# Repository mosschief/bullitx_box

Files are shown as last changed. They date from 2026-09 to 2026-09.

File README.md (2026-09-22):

# Bullitt X cargo box panels

Vermoot's plywood box for the Original Bullitt, stretched to fit a Bullitt X.

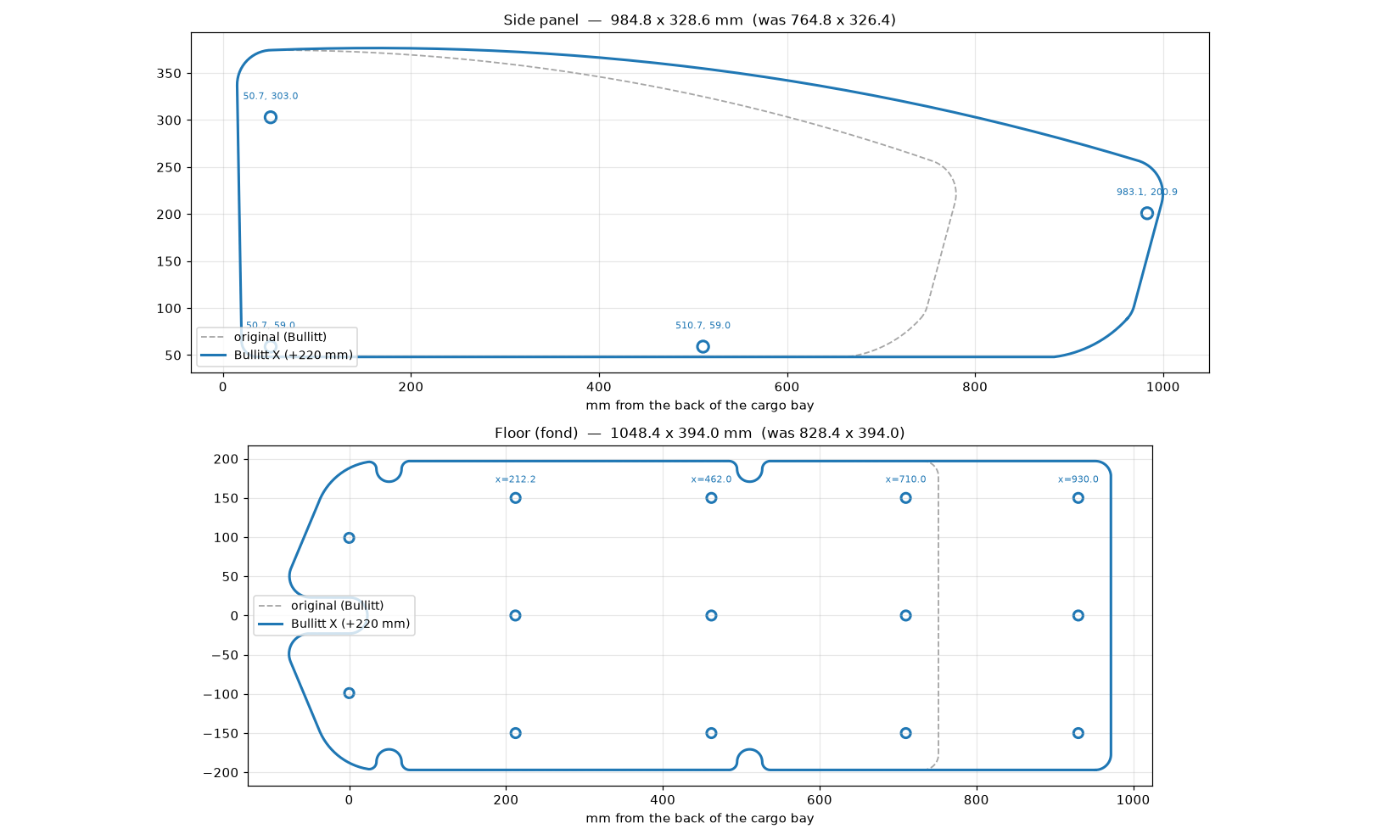
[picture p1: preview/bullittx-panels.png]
panels


## What changed, and why

The Bullitt X cargo bay is **220 mm longer than the Original Bullitt, and all of
the extra length is at the front**. Three things agree on this:

| | Original Bullitt | Bullitt X |
|---|---|---|
| Cargo bed at base (Larry vs Harry spec) | 710 mm | 930 mm |
| Cargo bed at top (Larry vs Harry spec) | 824 mm | 1044 mm |
| Total bike length (Larry vs Harry spec) | 2430 mm | 2650 mm |
| Floor transverses (from the two CAD models) | 3, at 212 / 462 / 710 | 4, at 212 / 462 / 712 / 932 |
| Inner width between the frame rails | 401 mm | 401 mm |

Line the two frames up by the back of the cargo bay and the Bullitt X's rear
cross brace and its first three floor transverses land on the Original's within
2 mm. The fourth transverse is new, 220 mm further forward. Bed top minus bed
base is 114 mm on both bikes, so the front and back walls lean at the same angle
and those two panels do not change at all.

So the panels are **not scaled**. Each one is cut through its straight middle
section and the front half is slid forward 220 mm. Every profile, radius and
bolt position at either end is exactly as Vermoot drew it.

## Files

Cut these two from 10 mm plywood, same as the originals:

- `panels/Side panel X.dxf` — 984.8 x 328.6 mm (was 764.8 x 326.4). Cut two, mirrored.
- `panels/fond X.dxf` — floor, 1048.4 x 394.0 mm (was 828.4 x 394.0).

**Unchanged — use Vermoot's originals as they are:** `front panel.dxf`,
`back panel.dxf`, `front link.stl`, `back link.stl`, `bottom link.stl`. They are
not copied into this repo; the design is Vermoot's and you already have it. Print
the same four bottom links, two back links and two front links as before.

## Bolt positions

x is measured from the back of the cargo bay, the same datum both DXFs already use.

**Side panel** — bottom-link bolts at x = 50.7 and 510.7 (both at y = 59),
back-link bolt at 50.7 / 303, front-link bolt at **983.1** / 200.9. Only the
front-link bolt moves; the other three are Vermoot's, untouched.

**Floor** — bolt rows at x = 212.2, 462, 710 and **930**, three bolts per row at
y = 0 and +/- 150. The first three rows are Vermoot's, unchanged; 930 is the new
fourth transverse. The two pairs of semicircular reliefs in the floor edge are
Vermoot's too, and stay where they are (see below).

## How the box hangs on the frame

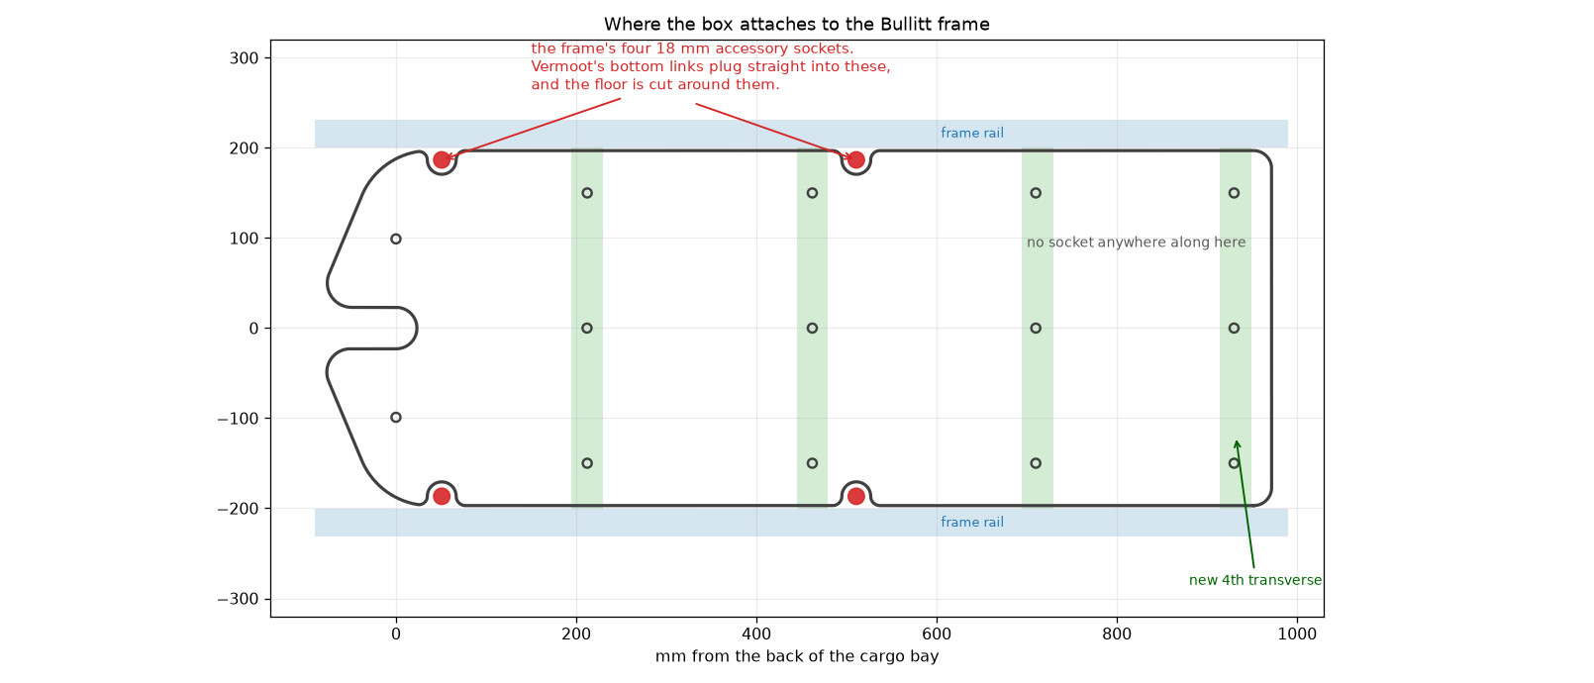
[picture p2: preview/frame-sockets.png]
frame sockets


The Bullitt frame has two cross tubes inside the cargo bay, at x = 50.8 and
510.8, each with an 18 mm vertical socket near either end at y = +/- 186.7.
**Vermoot's bottom link is a solid 18 mm peg that plugs into one of those
sockets** — it is not a clamp, and it will not mount anywhere else on the rail.
That is also what the semicircular reliefs in the floor edge are for: they clear
the socket and the foot of the link.

So the side panels have exactly four mounting points along the bottom and they
are fixed by the frame, not by the panel. A longer panel does not get more of
them. If your Bullitt X turns out to have a third pair of sockets further
forward, measure where they are and re-run the script with
`--extra-link-x <that x>`; it will add the panel bolt and the matching floor
relief. Otherwise the stretched panel runs unsupported along the bottom from
510.7 to the front link, 472 mm, which is 233 mm more than the original.

## Check this one dimension before you cut

The front-link bolt is at x = 983.1, which is Vermoot's 763.1 plus 220. The
Bullitt X model in `BullittX.FCStd` puts the front cross member about **9 mm
further forward and 9 mm lower** than a clean 220 mm shift predicts. That is
within the disagreement you would expect between two hand-built models — the
Bullitt model in the Vermoots project has its own cross beams at 250 and 248 mm
pitch, and puts the bed base at 715 mm where Larry vs Harry say 710 — but it
lands on the one hole that has no second bolt to average it out.

The cheap fix: cut the panel, offer it up, and drill the front-link hole last,
through the bracket, on the bike. Otherwise measure from the back of the bay to
the front link mount and compare with 983.

## Rebuilding the files

```
pip install ezdxf
python3 tools/make_bullittx_panels.py <folder with Vermoot's DXFs> panels/
python3 tools/preview.py <that folder> preview/bullittx-panels.png
```

`--extension` is the 220 mm, if you measure something different on your own bike.
`--extra-link-x` adds a bottom-link station, if your frame has a third socket pair.

## Cutting it on a CNC

`cnc/` has everything nested and ready to cut from 1/2" ply on a Shapeoko: the sheet
layouts as DXF and SVG, G-code, and the changes the thicker ply needs. Start with
[cnc/README.md](cnc/README.md).

## Fit check

`preview/fit-check.png` is the new geometry drawn over the Bullitt X frame from
`BullittX.FCStd`, aligned on the back of the cargo bay. The floor bolt rows
should sit on the red transverse marks.

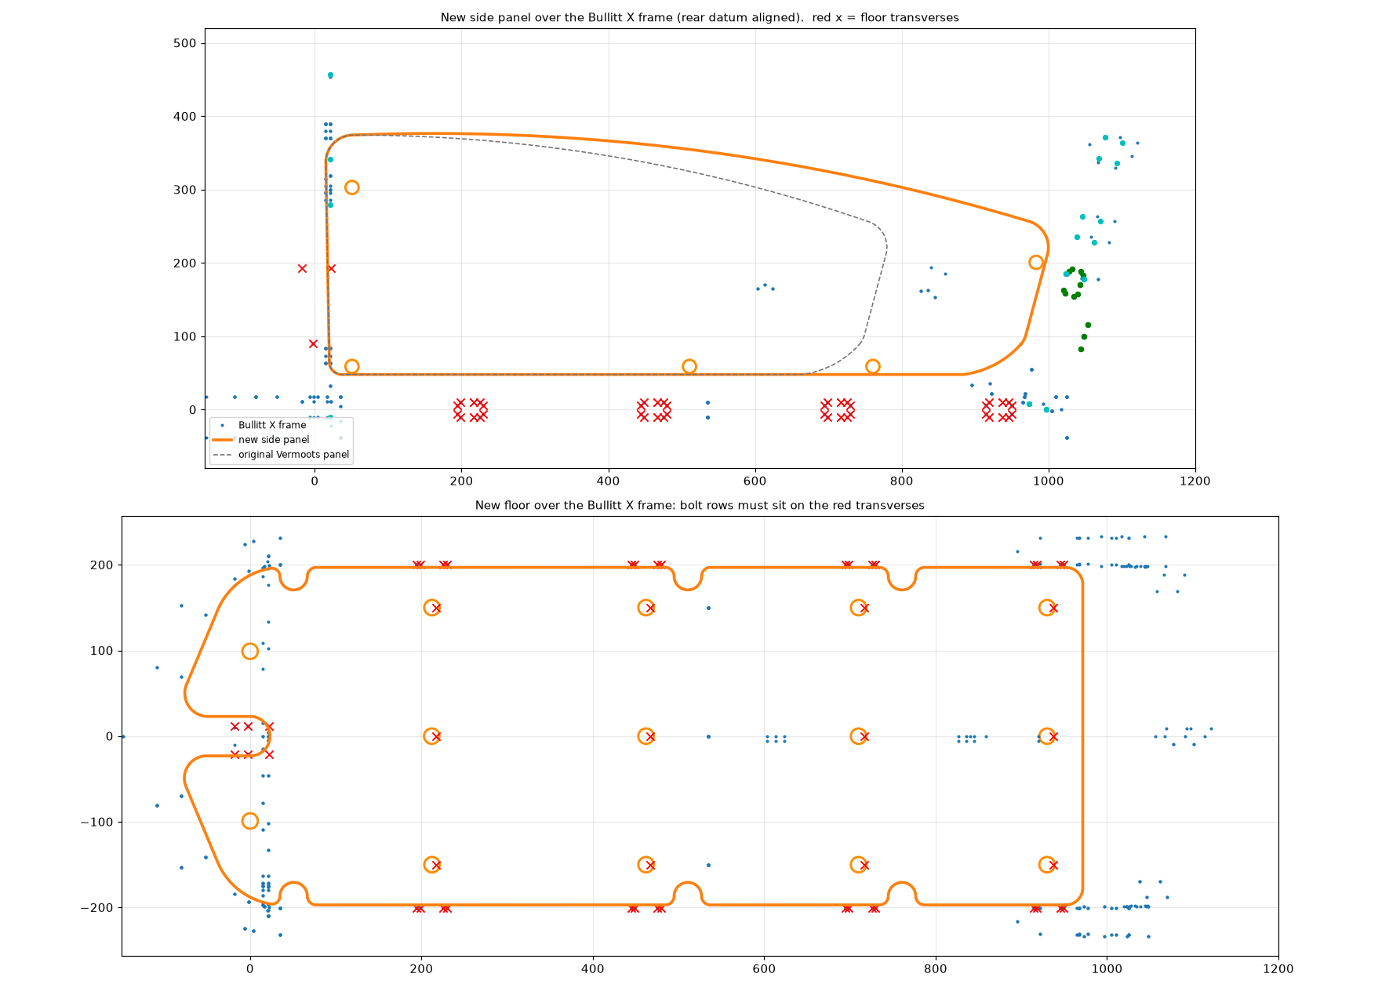
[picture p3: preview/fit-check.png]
fit check


## Child seat

The Larry vs Harry foldable seat bolts to the frame, not to the box, so the
220 mm stretch does not affect it and the Bullitt X gives it more room than a
standard Bullitt. What is worth checking before you commit: the box already
occupies all four of the frame sockets above, so if the seat wants the same
sockets, the two compete. The seat's own manual has its struts bolting to
"holes in the frame" from the outer side, and its lower bracket clamping the
shoulder tubes, which reads like a different set of mounting points — but that
is not confirmed. Dry-fit the seat before final assembly.

## Credit

The box design, the panel shapes and the three printed links are Vermoot's
"Plateformes Bullitt". This repo holds the two panels that had to change length,
the scripts that change them, and (under `cnc/`) all five panels adjusted and
nested for 1/2" ply.

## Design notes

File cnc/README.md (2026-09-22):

# Cutting the Bullitt X box on a Shapeoko 5 Pro from 1/2" ply

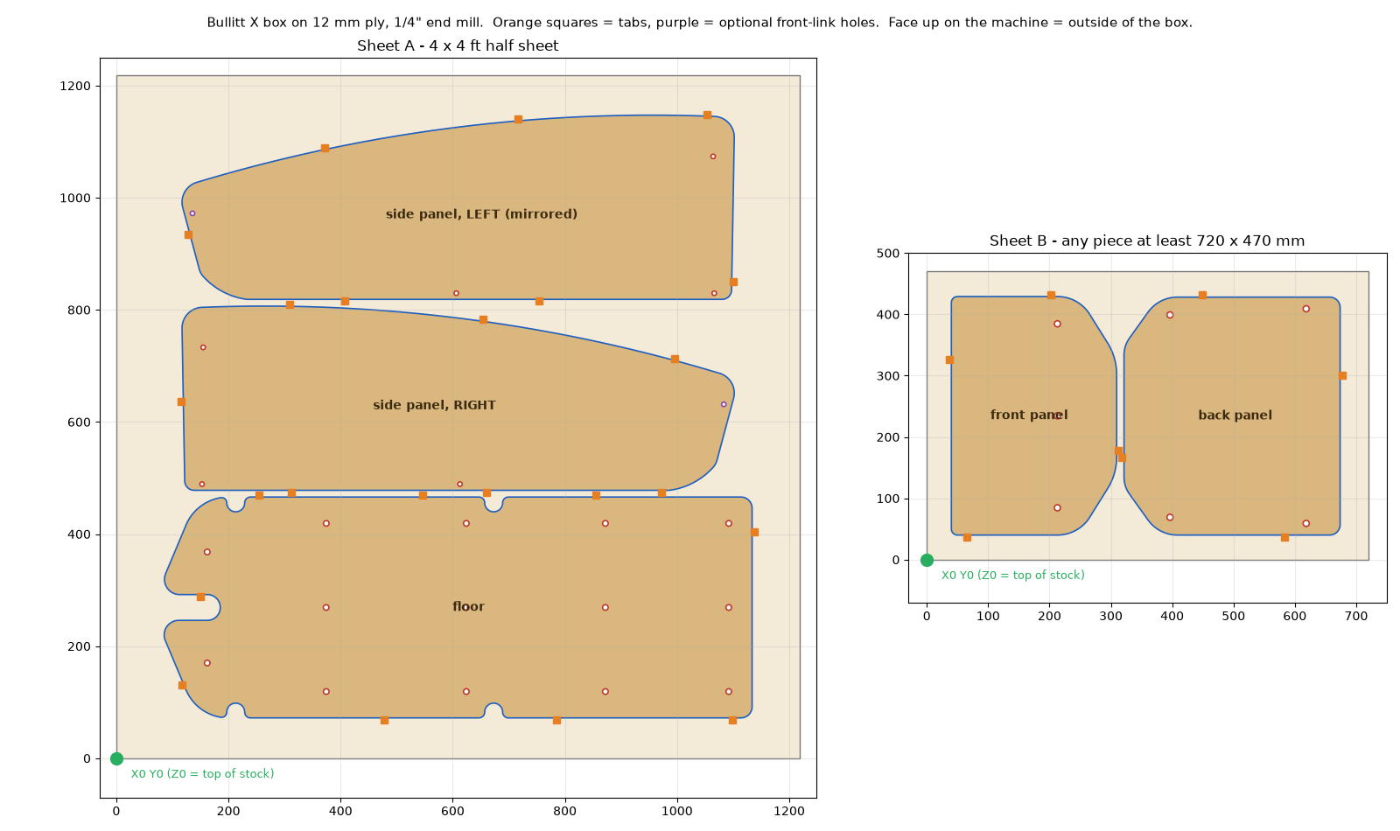
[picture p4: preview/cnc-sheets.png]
cut sheets


## It takes a half sheet plus a smaller piece

The floor and both side panels fill a 4 x 4 ft half sheet. The front and back
panels do not fit in what is left: the floor (394 mm) and the two side panels
(329 mm each) already use about 1075 mm of the 1219 mm, even nested tightly, and
the smallest side of the front panel is 271 mm. So:

| Sheet | Parts | Stock |
|---|---|---|
| **A** | floor, right side panel, left side panel | 4 x 4 ft half sheet |
| **B** | front panel, back panel | any piece at least **720 x 470 mm** (28.5 x 18.5 in); a 2 x 4 ft piece is plenty |

## Measure the ply, then pick the files

"1/2 inch" ply is usually 11.9 mm (15/32") or 12 mm (Baltic birch), sometimes a true
12.7 mm. Measure it with calipers in a few places and use the matching G-code:

| Measured thickness | Use |
|---|---|
| 11.7 to 12.3 mm | `gcode/*_12mm-stock.nc` (cuts 12.5 mm deep) |
| 12.4 to 13.0 mm | `gcode/*_12.7mm-stock.nc` (cuts 13.2 mm deep) |

Both cut about 0.5 mm into the spoilboard and leave 3 mm tabs.

## Machine setup

- **Tool:** 1/4" (6.35 mm) two-flute flat end mill. An upcut (Carbide 3D #201) works;
  a compression bit gives cleaner faces on both sides of the ply.
- **Spindle:** 18,000 rpm. On the Carbide router, set the dial by hand; the file sends `S18000`.
- **Feeds:** 1500 mm/min (59 ipm) cutting, 400 mm/min plunge, 800 mm/min in the holes,
  2.5 mm per lap. Deliberately conservative for a first run. Turn the feed override up
  if it sounds happy.
- **Zero:** X0 Y0 at the **front-left corner of the stock**, Z0 on the **top of the stock**.
  The BitZero corner probe does all three at once.
- **Safe height:** 15 mm above the stock. Keep clamps below that or out of the way of
  the parts.
- **Workholding:** every part stays attached by tabs (10 mm long, 3 mm thick; 9 on the
  floor, 7 per side panel, 4 each on the front and back). Screw the sheet down around the
  edge. Sheet A has at least 65 mm of clear margin all the way round. Put a few screws in
  the middle strips too if the sheet bows.

Each file cuts all its holes first, then each part outline. The outline is cut by
spiralling down 2.5 mm per lap with no plunges, followed by one clean-up lap at full
depth. Holes are helically bored with the same 1/4" bit (8 mm and 10 mm holes).

Rough run times at 100% feed: sheet A about 40 min, sheet B about 15 min.

## Run order

**Sheet A** (half sheet)
1. `sheet-A_floor-and-sides_front-link-holes-optional_<t>.nc`: **only if you want the
   front-link holes cut by the machine** (see below). Leave zero where it is.
2. `sheet-A_floor-and-sides_<t>.nc`

**Sheet B** (front/back piece)
1. `sheet-B_front-and-back_<t>.nc`

Cut the tabs with a flush-trim saw or chisel and sand them flush.

### The optional front-link holes

The side panel's front-link hole is the one dimension the previous check could not
pin down. The frame model puts that mount about 9 mm off where a clean 220 mm stretch
predicts. So it is in a separate file:

- Measure your bike first: the front link mount should be about 981 mm from the back
  of the cargo bay (the datum the main README uses). If it matches, run the optional file.
- If you're not sure, skip it, fit the panels, and drill the 8 mm hole through the bracket
  on the bike.

They are the purple holes in the picture above, and on their own layer
(`HOLES_front_link_optional`) in the DXF.

## Which side is which

Everything is cut with the **good face up**, so the face on top becomes the **outside**
of the box. The middle panel on sheet A is the **right** side panel (as Vermoot drew it)
and the top one is the **left** (mirrored). The floor, front and back panels are symmetric,
so either face can go up.

## What changed for 1/2" ply

The design was drawn for 10 mm ply. I thickened each panel in Vermoot's 3D assembly
(`Plateformes Bullitt Vermoot.step`) on the side it is free to grow and checked every
clash. Everything here is set for 12 mm. A true 12.7 mm sheet is only 0.7 mm off,
which the bolt holes and gaps absorb.

| Part | What happens with thicker ply | Change made |
|---|---|---|
| Side panels | Links bolt to the inside face, so they grow outward. The nearest frame tube is 7.8 mm away. | None to the outline |
| Front and back panels | Bolted to the frame by the outside face, so they grow into the box. The front and back links bolt to that inside face. | The front and back link bolt holes in the **side panel** move with the link: front one 1.9 mm back and 0.5 mm up (the front panel leans 15°), back one 2.0 mm forward |
| Floor | Sits on the cross beams and grows upward, eating Vermoot's 3 mm gap under the front and back panels (down to 0.2 mm at 12.7 mm). | **Bottom edge of the front and back panels trimmed 2 mm** to put the gap back |
| Bottom links | Peg into the frame and bolt to the side panel's inside face | None |
| Printed links | None of them change | Print as before: 2 front, 2 back, 4 bottom |

Other effects to know about:

- **Every bolt through the ply needs to be about 2 mm longer** (3 mm for 12.7 mm ply).
- The box is 4 mm wider outside (sides grow outward). Inside, it is 4 mm shorter and 2 mm shallower.
- The panels weigh about 20% more.

## Which plywood

1/2" is a good choice for the Bullitt X. It is 1.7 times as stiff as Vermoot's 10 mm,
and the stretched side panels now span 472 mm along the bottom edge between the
bottom link and the front link. The cost is weight: about 9.5 kg of panels in birch,
against 8 kg at 10 mm.

**What to ask for:** 12 mm Baltic birch with **exterior (WBP / phenolic) glue**, often
sold as "exterior" or "FSF" grade. Plain Baltic birch is often made with interior glue,
which delaminates once water gets into the edges.

| Plywood | Verdict |
|---|---|
| Exterior-glue Baltic birch, 12 mm | **Best all-round.** Void-free, machines cleanly, and the edges look good sealed. |
| Marine ply (BS 1088 okoume), 12 mm | Very weatherproof and about 25% lighter than birch. It costs more, and the soft face dents. |
| Interior Baltic birch or hardwood ply | Fine only if the bike lives indoors and gets sealed well. |
| CDX / sheathing | Avoid. It has voids, splinters on the CNC, and the edges soak up water. |

Baltic birch usually comes in 5 x 5 ft sheets. Sheet A needs a 4 x 4 piece; the
leftover strip is too narrow for the back panel (354 mm), so sheet B still needs a
second piece unless the files are re-nested for a 5 x 5 sheet.

**Weatherproofing.** The edges are what fail, so seal them before anything else, and
do the faces and holes after that:

1. Round the edges over (1 to 2 mm) and sand to 180 grit.
2. Seal everything, edges and bolt holes included. Use either a penetrating epoxy sealer
   followed by 2 or 3 coats of exterior spar varnish, or an exterior primer followed by
   2 coats of exterior paint. Epoxy gives the best protection, and paint is the cheapest
   and easiest to touch up.
3. Leave the 3 mm gaps under the front and back panels open so water can drain.

## Shopping list

Vermoot's files don't list hardware, so these sizes come from his 3D assembly. Every
bolt was traced through the parts it clamps, then 2 mm was added for the thicker ply.
The 8 mm holes (side panels and printed links) take **M6**. The 10 mm holes (floor,
front and back panels) take **M8**.

**Check one thing before you buy.** The model shows the frame's mounting points as plain
10 mm holes, so this list assumes bolts go all the way through with a nyloc nut behind.
Try an M6 and an M8 bolt in one of the floor mounting points and one of the rear frame
tabs on your bike. If they thread in, you don't need the nuts and the frame bolts can be
much shorter.

### Bolts
Use stainless A2 (A4 if you ride near salt), in button-head hex or hex-head style.

| Bolt | Qty | Where it goes | What it clamps |
|---|---|---|---|
| M6 x 30 | 8 | Side panels to the 8 printed links, 4 per side | 12 mm ply + 4 mm link |
| M6 x 35 | 2 | Back links through the back panel into the rear frame tabs | 4.5 mm link + 12 mm ply + 4 mm tab |
| M6 x 50 | 2 | Front links through the front panel and the front frame | 4.5 mm link + 12 mm ply + 20 mm tube |
| M8 x 35 | 2 | Back panel, lower corners, to the rear frame tabs | 12 mm ply + 4 mm tab |
| M8 x 50 | 13 | Floor to the 4 cross beams (12), front panel centre to the front frame (1) | 12 mm ply + 20 mm tube |
| M8 x 65 | 2 | Floor tongue to the rear cross brace | 12 mm ply + 35 mm brace |

### Nuts and washers

| Part | Qty |
|---|---|
| M6 nyloc nut | 12 |
| M8 nyloc nut | 17 |
| M6 washer, large OD ("fender", about 18 mm) for the wood side | 8 |
| M6 washer, standard, for the link or frame side | 16 |
| M8 washer, large OD (about 24 mm) for the wood side | 17 |
| M8 washer, standard, for the frame side | 17 |

Buy a few spares of each.

### Printed links

| Part | Qty |
|---|---|
| `bottom link.stl` | 4 |
| `front link.stl` | 2 |
| `back link.stl` | 2 |

Every link is symmetric, so the same file works on both sides and nothing needs
mirroring. All eight together are about 120 cm³ of plastic, or roughly 160 g of PETG
printed solid, so **one 1 kg spool** is plenty.

Use **PETG or ASA, not PLA**. PLA creeps under load and goes soft on a bike parked in
the sun. For strength, print with 5 walls and 40% or more infill.

### Wood and finish

- 1 x 4 x 4 ft sheet of 12 mm exterior Baltic birch (sheet A)
- 1 x piece at least 720 x 470 mm of the same (sheet B); a 2 x 4 ft piece covers it
- Penetrating epoxy sealer plus exterior spar varnish, or exterior primer plus paint:
  about 1 litre (1 quart) of each is enough for both sides and every edge
- 180-grit sandpaper
- 1/4" two-flute end mill (see Machine setup)

## Files

| File | What it is |
|---|---|
| `sheet-A_floor-and-sides.dxf` / `.svg` | Nested sheet A in mm, for Carbide Create or anything else |
| `sheet-B_front-and-back.dxf` / `.svg` | Nested sheet B |
| `gcode/*.nc` | Ready-to-run G-code as above |
| `parts/*.dxf` | Each part on its own, adjusted for 12 mm ply |

The DXFs and SVGs include the stock outline (layer `STOCK_OUTLINE_do_not_cut` or the grey
rectangle). Use it to line the drawing up with your stock, then delete it.

### Doing it in Carbide Create instead

Import the sheet SVG (it is sized in mm). Check the floor reads 1048.4 mm long. Set the
stock to the sheet size and measured thickness, with zero at the lower-left and on top. Then:

- **Contour, inside**, on the holes
- **Contour, outside**, on the parts, with tabs

Use the same tool and feeds as above.

## Checking or regenerating

```
pip install ezdxf shapely matplotlib
python3 tools/make_cnc.py <folder with Vermoot's DXFs>            # writes cnc/ and preview/cnc-sheets.png
python3 tools/backplot.py out.png cnc/sheet-A_floor-and-sides.dxf cnc/gcode/sheet-A_*12mm-stock.nc
```

`make_cnc.py` takes `--thickness` for the geometry and `--gcode-stock` for the depths,
plus the tool, feeds, tab and spacing settings. `backplot.py` reads the G-code back and
checks it against the nested DXF. Each file here passed with no gouges, nothing outside
the stock, every hole and outline cut through, and tabs only where intended.
`preview/backplot-sheet-A.png` shows the result for sheet A.

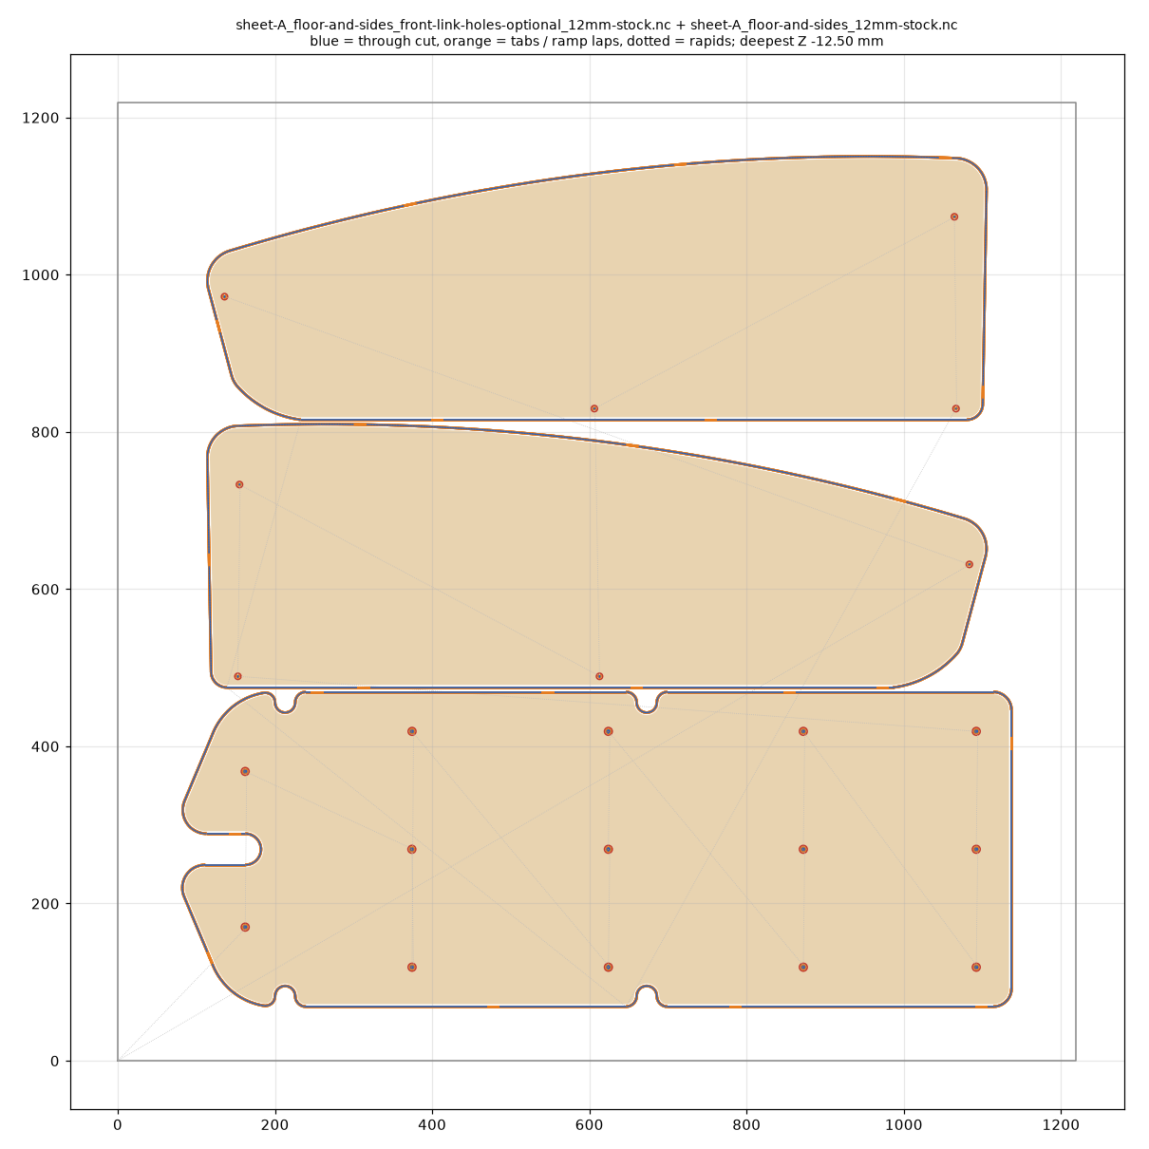
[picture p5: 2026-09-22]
preview/backplot-sheet-A.png

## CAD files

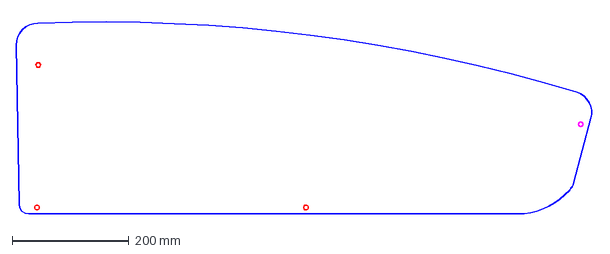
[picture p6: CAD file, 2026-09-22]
cnc/parts/Side panel X (12mm ply).dxf
988.7 x 338.7 mm

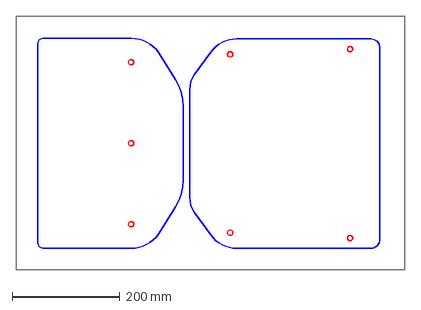
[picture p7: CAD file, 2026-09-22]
cnc/sheet-B_front-and-back.dxf
720.0 x 470.0 mm

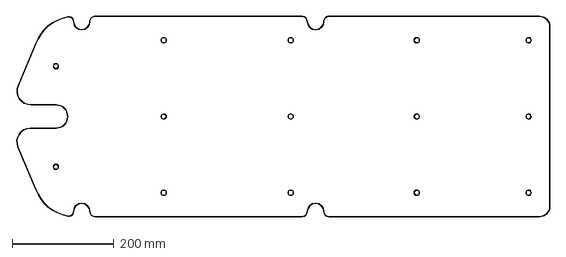
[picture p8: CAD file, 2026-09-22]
panels/fond X.dxf
1049.8 x 394.0 mm

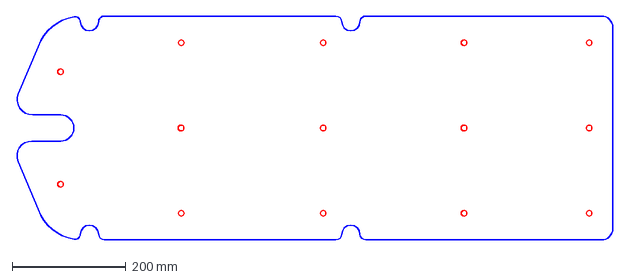
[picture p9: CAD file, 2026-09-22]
cnc/parts/fond X (12mm ply).dxf
1049.8 x 394.0 mm

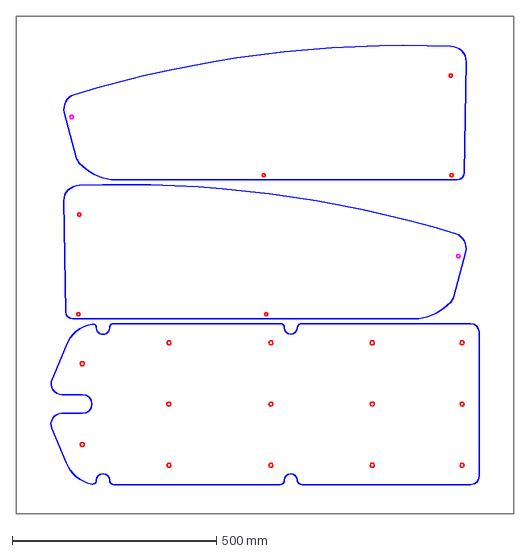
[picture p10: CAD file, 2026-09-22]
cnc/sheet-A_floor-and-sides.dxf
1219.2 x 1219.2 mm

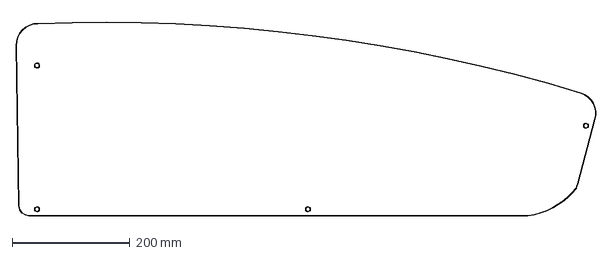
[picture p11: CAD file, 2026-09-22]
panels/Side panel X.dxf
988.7 x 338.7 mm

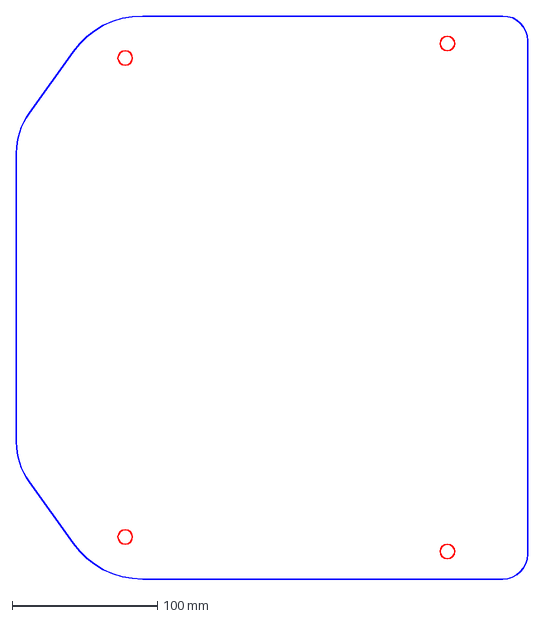
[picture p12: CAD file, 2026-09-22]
cnc/parts/back panel (12mm ply).dxf
352.3 x 388.0 mm

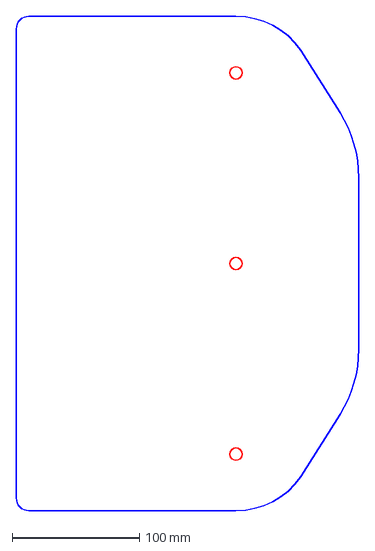
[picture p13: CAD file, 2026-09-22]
cnc/parts/front panel (12mm ply).dxf
269.5 x 389.0 mm

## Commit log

2026-09-22 Add Bullitt X cargo box panels stretched from the Vermoots design
    The Bullitt X cargo bay is 220 mm longer than the Original Bullitt, all of it
    at the front. Aligning the two frames on the back of the bay, the Bullitt X's
    rear cross brace and first three floor transverses land on the Original's
    within 2 mm and a fourth transverse sits 220 mm further forward; Larry vs
    Harry's own figures agree (bed base 710 -> 930, bed top 824 -> 1044, total
    length 2430 -> 2650).
    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
    [Side panel X.dxf, fond X.dxf]
2026-09-22 Add CNC cut files for 1/2" ply on a Shapeoko
    Nest all five panels (floor and sides on a 4x4 half sheet, front and back on a
    second piece), adjust the geometry for 12 mm ply, and write DXF, SVG and G-code
    with tabs, helical holes and spiral profiles. Includes a backplot checker.
    Claude-Session: https://claude.ai/code/session_01JvYrkRmtAMDStvvZxb2krL
    [Side panel X (12mm ply).dxf, back panel (12mm ply).dxf, fond X (12mm ply).dxf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]
2026-09-22 Drop the third bottom link: Vermoot's link is a socket plug, not a clamp
    Sectioning bottom link.stl shows the part is a solid 18 mm peg running from
    z = -25 to +27, coaxial with an 18 mm vertical socket that the Vermoots frame
    model places at x = 50.8 and 510.8, y = +/- 186.7. It plugs into the frame's
    accessory sockets rather than clamping the rail, so the extra mount added at
    x = 760.7 had nothing to bolt to. The semicircular reliefs in the floor edge
    clear those sockets and the feet of the links, which is why they sit at exactly
    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
    [Side panel X.dxf, fond X.dxf]
2026-09-22 Regenerate CNC files without the third bottom link
    The corrected side panel and floor (52669a7) drop the extra bottom-link bolt
    and floor relief, since there is no frame socket for it. Sheet A DXF, SVG and
    G-code rebuilt from them and re-checked with backplot.py; sheet B is unchanged.
    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
    [Side panel X (12mm ply).dxf, back panel (12mm ply).dxf, fond X (12mm ply).dxf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]
2026-09-22 Add plywood advice and hardware shopping list to the cut sheet
    Bolt sizes and lengths come from tracing every hole through Vermoot's STEP
    assembly and adding the 2 mm for 12 mm ply; includes nuts, washers, printed
    links and finish.
    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
2026-11-07 Add a folding rain hood for 1/2" ply
    Three ply hoops pivot on printed hubs bolted through Vermoot's back-link
    hole (M6, at its 12 mm ply position), with printed elbows, a friction knob,
    and an apron press-studded to the side panels. canopy_parts.py builds the
    printed and ply parts and checks for collisions hood up and folded.
